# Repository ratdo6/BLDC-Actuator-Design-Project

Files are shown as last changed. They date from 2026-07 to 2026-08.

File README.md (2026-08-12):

<div align="center">

# BLDC Cycloidal Actuator - Quadruped Robot Leg

Inexpensive · Teensy 4.1 · Backdrivable · 3D printed · Moteus r4.11 FOC · CAN bus · Low backlash · ROS2 · BLDC motor



</div>

A custom cycloidal gearbox and actuator designed for a quadruped robot. Built around an 8308 BLDC motor, mjbots moteus r4.11, teensy 4.1, 3D printing, and ROS2. It takes advantage of the easy to manufacture cycloid geometry to create a cheap, but efficient actuator. This project is an opportunity for me to learn new skills and hone my strengths as an engineer. It is still in the early phases of development.  

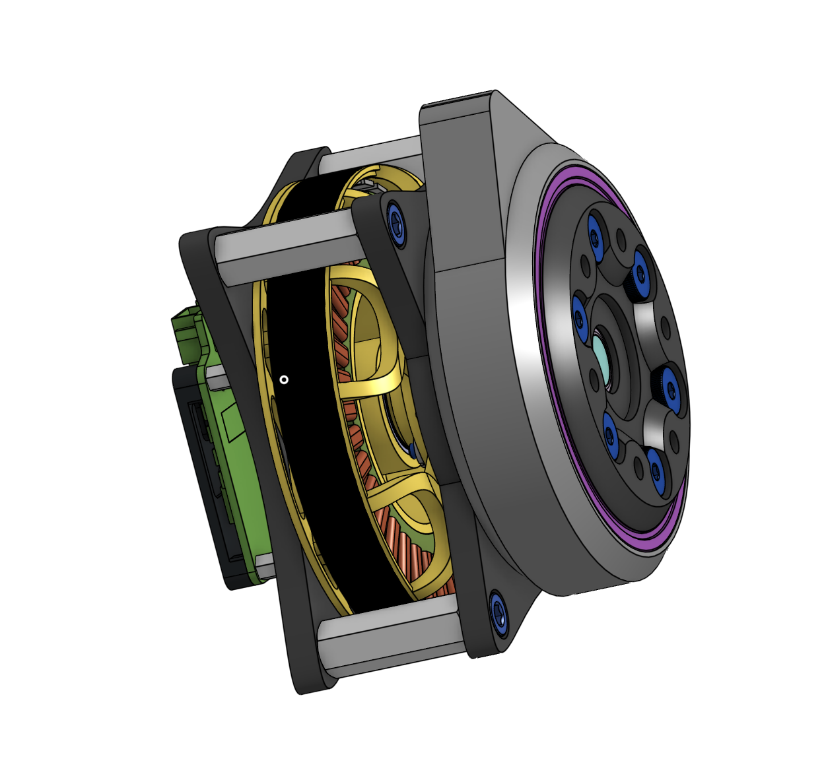
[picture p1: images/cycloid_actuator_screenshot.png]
Gearbox Assembly


## Goals

- **Plays nice with ROS2** — built to hook into ROS2 for the higher-level brain stuff (motion planning, orchestration, etc) 
- **Quadruped ready** — designed around a 12-DOF, 4-leg setup, but flexible enough to be repurposed
- **Precise joints** — actuator and drivetrain picks aim for minimal backlash, so movement stays accurate instead of sloppy
- **Custom electronics** — custom hub PCB handles CAN routing, power distrubution, and sensors avoiding the mess of breakout boards and jumper wires
- **3D-printable/sourceable** — Parts are deisgned to be FDM printer friendly or easily sourceable online 
- **Actually documented** — schematics, step files, firmware, design decisions, etc are all written up so I (or anyone else) can actually follow along and buid it

## Status

- [x] Cycloidal disc design, [Python visualizer](cycloidal_drive_visualizer/cycloidal_drive_visualizer.py)
- [x] Actuator design, [CAD](CAD/onshape_link.md)
- [x] [Bill of materials (BoM)](BOM/cycloidal_actuator_BOM.xlsx) (rough version available)
- [x] Calibrate Moteus r4.11 controllers to BLDC motors
- [x] 3D Printed protoype, tolerances dialed
- [ ] [KiCad PCBA schematic](Kicad-schematic/Teensy_BLDC_Build/Teensy_BLDC_Build.kicad_sch)
- [ ] Teensy 4.1 software
- [ ] Actuator efficiency and backlash testing
- [ ] Full 3DOF Leg Design
- [ ] Demo video(s)
- [ ] All CAD uploaded in .STEP & .STL formats

## Design Overview

Actuator architecture is built around a cycloid drive paired with a BLDC motor and FOC controller, chosen for its combination of high reduction ratio, low backlash, and shock tolerance. Crossed roller bearings are used at joint interface to handle combined radial and axial loads with minimal play. All design choices were picked with a legged robot in mind that has to absorb impact loads on every step.

- **Reduction ratio:** 9:1 (allows backdrivability, 10 roller pins, 9 lobes on disc)
- **E / Rr:** 0.500 (eccentricity (E) = 1.25mm)
- **Max pressure angle:** 20.03 degrees
- **Disc material:** PLA+ (future exploration into machined nylon, delrin, or aluminum planned)
- **BLDC motor:** Eagle Power 8308 90kv (cheap, powerful, and readily available)
- **FOC controller:** Moteus r4.11 (CAN bus interface, closed loop, compact form factor)

A custom built [cycloid disc parameters visualizer](cycloidal_drive_visualizer/cycloidal_drive_visualizer.py) was used to optimize variable selection before beginning CAD modeling
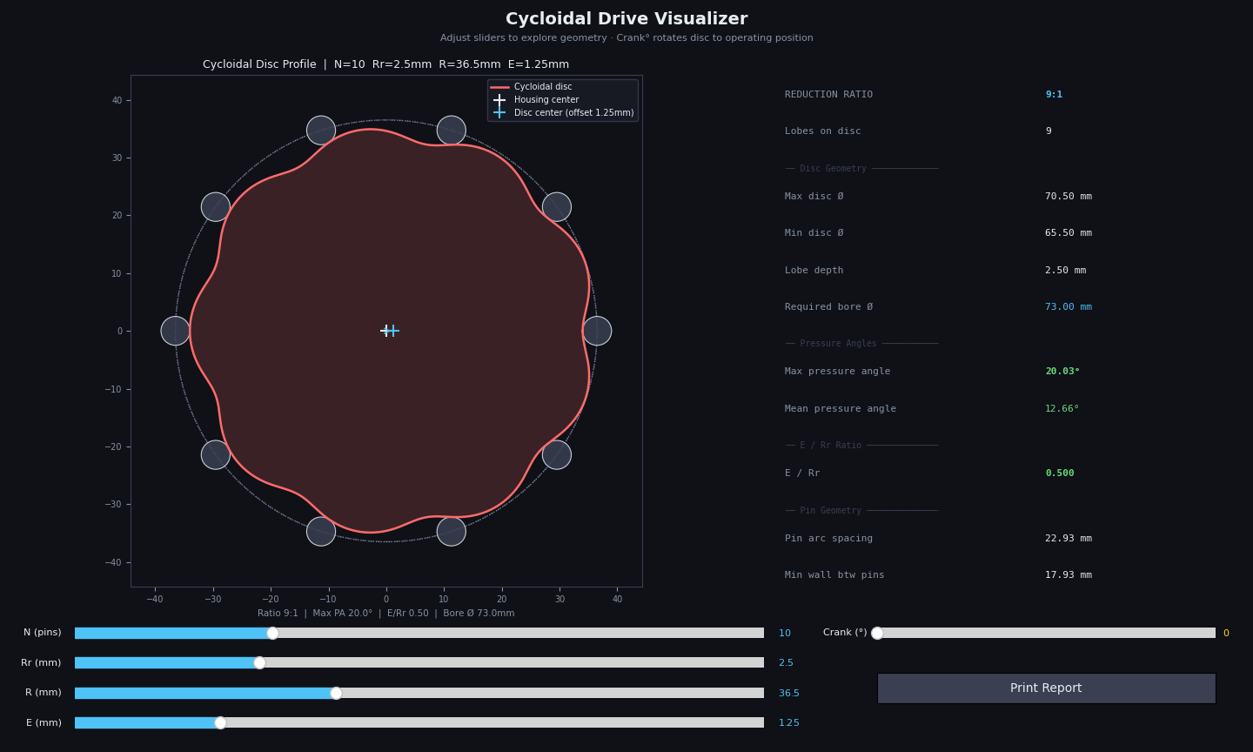
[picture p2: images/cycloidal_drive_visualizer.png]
Cycloidal Drive Visualizer


All CAD designed in OnShape. [View OnShape Document](https://cad.onshape.com/documents/7e181885841e2c0563f5ea8b/w/eb359d6e40468758aae61fb6/e/6c3a266b2d21d51902da69a4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)
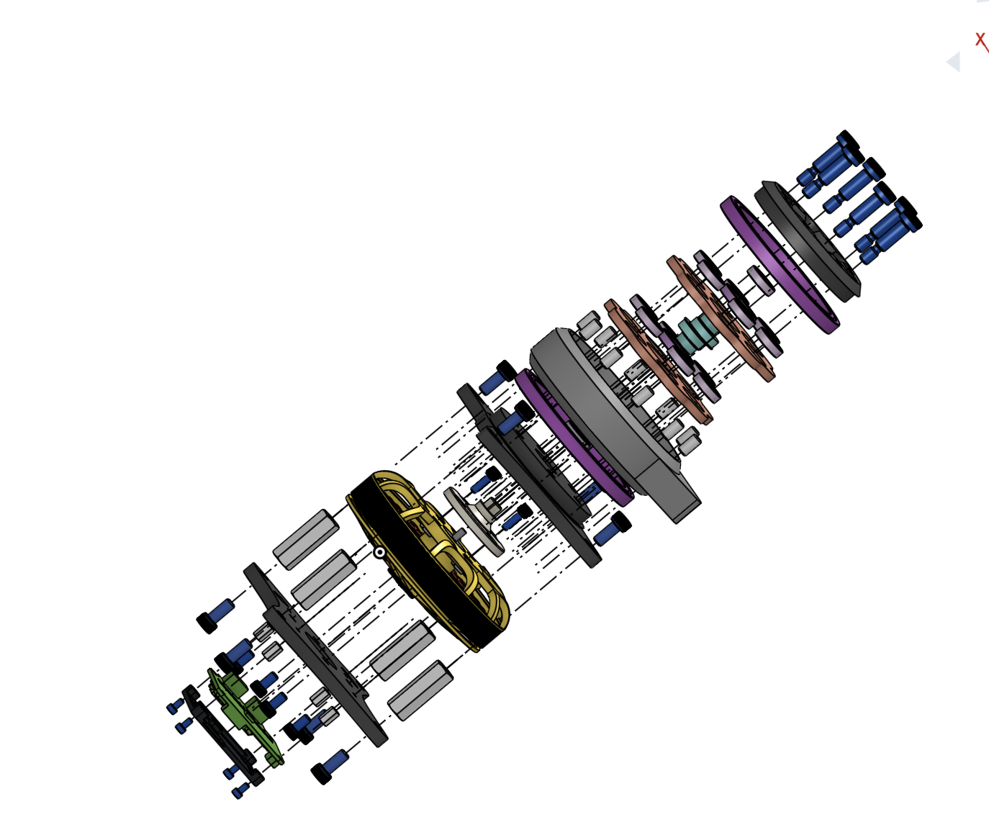
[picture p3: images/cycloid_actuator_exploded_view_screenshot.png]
Gearbox Assembly Exploded View


The actuator design centers on three choices that reinforce the same goal of minimal backlash, without needing industrial manufacturing access.

Cycloidal reduction was chosen over harmonic, planetary gearing, or capstan drives as the best fit for a self-built project. Harmonic drives offer great backlash performance but rely on flex-splines that are hard to source or machine yourself. Planetary gearboxes are easier to source but need precision-ground components to match cycloidal-level backlash. Capstan drives offer great performance for cost but are bulky and difficult to integrate in a compact leg assembly. Cycloidal drives split the difference — mechanically simple, tolerant of imperfect fabrication, compact, and low-backlash by design.

BLDC + FOC control (via the Moteus r4.11) keeps torque output smooth, which matters since any motor cogging gets amplified through the reduction stage. It also keeps the system modular, each joint handles its own closed-loop control over CAN, so the central hub just sends setpoints instead of managing low-level control for all 12 actuators.

Cross roller bearings at the output stage protect my backlash budget end-to-end. A precise cycloidal stage doesn't help if the output shaft has play. These bearings handle the combined radial/axial loads of stance and impact in a compact footprint, keeping joint mass reasonable for leg dynamics.

Together, these choices aim for locomotion-grade precision using parts and processes an individual builder can actually access.

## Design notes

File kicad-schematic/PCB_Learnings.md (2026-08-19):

# PCB Learnings:

The Teensy 4.1 is socketed, must preserve USB access, and avoid unsade USB/VIN back-power paths

Prefer the simplest physcically linear bus topology that matches the electrical constraints; adding more branches can make the system 
look simpler mechanically but usually hurts signal integrity and makes termination harder.

Mount the IMU rigidly on the PCB rather than making it removable, because mechanical rigidity improves motion measurement consistency 
and avoids extra cost and height.

Prefer removable, socketed mounting for high-value modules, but keep low-cost, vibration-sensitive signal parts permanently soldered 
for better reliability and measurement stability.

Prefer socketed or high-retention mounting for removable regulator modules over loose jumper-wire connections, 
because jumpers add failure points in vibrating systems.

For robot hubs that need orientation data, 
a fused IMU with onboard sensor fusion is often the cleaner choice than raw inertial sensing plus host-side fusion.

Verify the physical-layer transceiver is CAN-FD rated before committing to the design; 
classic CAN transceivers are not suitable for the higher data-phase bitrate.

For a central-hub robot, it is often cleaner to treat the hub as a passive CAN junction and keep motor power distribution on a separate board, 
so the communication board only has to handle logic, transceivers, and low-power peripherals.

A linear daisy-chain CAN-FD bus with short stubs and end-only termination 
can still be practical over roughly 4.5 m for a small multi-node robot.

If the processor only has one CAN-FD-capable controller, 
two independent CAN-FD buses may require an external CAN-FD controller or a different MCU architecture.

Classic CAN transceivers are not suitable for CAN-FD data-phase rates;
the CAN physical layer choice must be checked against the actual bus protocol requirements, not just the arbitration bitrate.

# Project Specification

## Project Overview
- Teensy 4.1 carrier and central control hub for a quadruped robot.
- Accepts 24 VDC and provides local 5 V power through a removable Pololu D24V50F5 module.
- Interfaces one Teensy 4.1 CAN-FD controller to twelve moteus r4.11 motor controllers on one linear CAN-FD bus.
- Includes a permanently assembled fused 9-DoF IMU.

## Intended Use
- Prototype and robot-development platform mounted near the center of a quadruped.
- Initial use may test one three-motor leg; the completed wiring supports all four legs.
- Expected CAN cable length is approximately 4.5 m end-to-end in the complete robot.

## What the Device Should Do
- Power a socketed Teensy 4.1 from a 24 V robot supply.
- Communicate with up to twelve moteus r4.11 FOC controllers.
- Acquire fused orientation and motion data.
- Permit rapid replacement of the Teensy and DC-DC module.
- Provide accessible test points and mechanically secure robot-ready connections.

## Main Features
- XT30 24 VDC input used only by the hub.
- Socketed Pololu D24V50F5 5 V regulator module.
- Socketed Teensy 4.1.
- One MCP2562FD-class CAN-FD transceiver with 3.3 V VIO and at least 5 Mbit/s capability.
- Two JST-PH 3-pin CAN connectors: CANH, CANL, GND.
- BNO085/BNO086-class IMU using SPI.
- Input protection, local decoupling, status indication, and test access.
- Four M2.5 corner mounting holes.

## System Architecture
```mermaid
flowchart TD
    VIN["24 VDC XT30 Input"] --> PROT["Input Protection"]
    PROT --> POL["Socketed Pololu D24V50F5"]
    POL --> V5["5 V Rail"]
    V5 --> TEENSY["Socketed Teensy 4.1"]
    TEENSY --> V3.3["3.3 V Rail"]
    V3.3 --> IMU["BNO08x IMU"]
    V3.3 --> CANPHY["CAN-FD Transceiver"]
    TEENSY --> IMU
    TEENSY <--> CANPHY
    CANPHY <--> CAN_A["CAN Connector A"]
    CANPHY <--> CAN_B["CAN Connector B"]
    CAN_A <--> LEGS_A["Six moteus r4.11 Controllers"]
    CAN_B <--> LEGS_B["Six moteus r4.11 Controllers"]
```

## Hardware Subsystems
### Power
- XT30 input, nominal 24 VDC.
- Add reverse-polarity and transient protection appropriate for wiring in a motorized robot.
- Pololu D24V50F5 remains removable through high-retention socket headers and mechanical support provisions.
- Teensy VIN receives regulated 5 V; do not connect an external 5 V source simultaneously without respecting Teensy power-input constraints.

### Compute
- Teensy 4.1 on removable female socket headers.
- Use the Teensy CAN3/CAN-FD-capable interface.
- Preserve USB connector access, reset/program access, and SD-card access where practical.

### CAN-FD
- One physical bus at 1 Mbit/s arbitration and 5 Mbit/s data phase.
- Two connectors represent the two physical directions of one linear bus, not independent channels.
- No onboard 120 ohm termination in the default design. Termination belongs at the two physical ends; the user has external JST-PH terminator boards for reduced configurations.
- CANH/CANL routing must be short, symmetric, and treated as a controlled differential pair.
- Add CAN-line ESD protection with low capacitance suitable for CAN-FD.

### IMU
- Permanently assembled BNO085/BNO086-class fused IMU.
- SPI interface preferred for reliable higher-rate communication.
- Mount near the board center, rigidly, with clear axis markings.
- Keep away from the switching regulator, high-current paths, and magnetic materials where possible.

## Interfaces and Connections
| Interface | Connector or Device | Signals |
|---|---|---|
| Power input | XT30 | +24V, GND |
| CAN direction A | JST-PH 3-pin | CANH, CANL, GND |
| CAN direction B | JST-PH 3-pin | CANH, CANL, GND |
| Host compute | Teensy 4.1 sockets | 5V, 3.3V, GND, CAN TX/RX, SPI, interrupt/reset signals |
| Regulator | Pololu D24V50F5 sockets | VIN, GND, VOUT and applicable control pins |
| Debug/test | Test points | 24V, 5V, 3.3V, GND, CANH, CANL, CAN TX, CAN RX, SPI CS/IRQ |

## Power and Runtime Expectations
- The hub does not distribute motor power.
- Continuous power is expected to remain well below the Pololu module's 5 A rating.
- Design for at least 0.75 A available on the 5 V rail to cover Teensy activity, USB peripherals, CAN dominant-state current, IMU, indicators, and margin.

## Power Tree and Power Budget
| Rail | Load | Estimated Typical | Design Peak |
|---|---|---:|---:|
| 5 V | Teensy 4.1 and attached local functions | 150-250 mA | 500 mA |
| 5 V | CAN-FD transceiver bus supply | 10-40 mA | 80 mA |
| 3.3 V | BNO08x IMU | 5-15 mA | 25 mA |
| 3.3/5 V | LEDs and support circuitry | 5-15 mA | 30 mA |
| 5 V total | All hub loads plus margin | about 300 mA | 750 mA design target |

At 24 V and 90 percent conversion efficiency, a 0.75 A peak at 5 V corresponds to approximately 0.174 A from the 24 V input. Protection and connectors should be sized above this with transient margin. Final values must be checked against selected part datasheets and any later Teensy USB/peripheral loading.

## Manufacturing and Assembly Expectations
- Four-layer PCB preferred for solid ground/reference planes and robust CAN-FD routing.
- Manufacturer assembles all SMD parts, connectors, protection, and IMU.
- Teensy and Pololu modules remain removable and may be installed after PCBA delivery.
- Choose commonly stocked, non-obsolete parts where possible.
- Include fiducials, readable polarity and pin-1 markings, connector pin labels, IMU axes, and board revision marking.

## Firmware-Relevant Hardware Requirements
- Teensy 4.1 CAN3 configured for CAN-FD, 1 Mbit/s nominal and 5 Mbit/s data rate.
- SPI interface to BNO08x with dedicated chip-select, interrupt, and reset as required.
- Maintain access to Teensy USB programming and program/reset controls.
- Firmware must support operation with one to twelve moteus nodes and report CAN errors.

## Physical Design Expectations
- Compact rectangular board sized after footprint and connector placement.
- Four M2.5 clearance mounting holes at the corners.
- XT30 and CAN connectors accessible from board edges.
- Teensy USB connector accessible at an edge.
- IMU close to mechanical center with axis legend on silkscreen.
- Provide mechanical support/retention provisions for both removable modules.

## Important Design Decisions
- One shared linear CAN-FD bus was selected because Teensy 4.1 exposes one CAN-FD-capable controller.
- Two CAN connectors represent opposite directions of the bus; each direction daisy-chains through six moteus controllers.
- MCP2562FD-class transceiver selected over SN65HVD230 because SN65HVD230 is unsuitable for the 5 Mbit/s CAN-FD data phase.
- Teensy and Pololu modules are removable; IMU and CAN interface are permanently assembled for signal integrity and mechanical stability.
- No onboard termination; external termination is placed at actual bus ends.

## Assumptions
- The complete cable assembly is a true linear trunk with very short moteus stubs.
- The robot supply can experience motor-related transients; input protection will be included even though motor power is routed elsewhere.
- JST-PH cable pin order will be fixed consistently as CANH, CANL, GND and clearly marked.
- Environmental target is indoor prototype robotics rather than sealed outdoor deployment.

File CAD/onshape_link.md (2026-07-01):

# CAD Files

All CAD was deisgned in OnShape.

[View OnShape Document](https://cad.onshape.com/documents/7e181885841e2c0563f5ea8b/w/eb359d6e40468758aae61fb6/e/6c3a266b2d21d51902da69a4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)

## Notes
- Primary design tool: OnShape
- Exported formates: .step

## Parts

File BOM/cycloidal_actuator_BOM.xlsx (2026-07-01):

CYCLOIDAL ACTUATOR — BILL OF MATERIALS
8308 Motor | 9:1 Ratio Cyloidal Actuator
# | Name | Description / Spec | Qty | Unit | Unit Cost ($) | Total Cost ($) | Link
BEARINGS
1 | KA025XP0 BEARING | KA025XP0, Crossed Roller Bearing, OD 72.2 x ID 63.5 x W 6.35 mm | 2 | ea | $10.77 | $21.54 | https://www.alibaba.com/product-detail/KA025XP0-KA025XPO-Size-63-5x76-2x6_1600117064347.html
2 | 6700ZZ BEARING | 6700ZZ, Deep Groove Ball Bearing, ID 10 × OD 15× W 4 mm | 14 | ea | $0.74 | $10.36 | https://www.amazon.com/uxcell-Deep-Groove-Bearings-Rollers-Skateboard/dp/B0D9DLHGV4
3 | 6702ZZ BEARING | 6702ZZ, Deep Groove Ball Bearing, ID 15 x OD 21 x W 4 mm | 2 | ea | $0.95 | $1.90 | https://www.amazon.com/uxcell-Deep-Groove-Bearings-Rollers-Skateboard/dp/B0D9DMY13D
ROLLERS
4 | M5x10mm DOWEL PIN | Dowel Pin, M5 x 10mm 304 Stainless Steel | 10 | ea | $0.24 | $2.40 | https://www.amazon.com/HARFINGTON-Stainless-Cylindrical-Furniture-Installation/dp/B0FW41S6QM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
CUSTOM PARTS
5 | CYCLOIDAL DISC | FDM Printed with PLA+, 40% Infill | 2 | ea | $1.00 | $2.00 | N/A
6 | ECCENTRIC SHAFT | FDM Printed with PLA+, 40% Infill | 1 | ea | $1.00 | $1.00 | N/A
7 | SHAFT COUPLER | FDM Printed with PLA+, 40% Infill | 1 | ea | $1.00 | $1.00 | N/A
8 | HOUSING | FDM Printed with PLA+, 40% Infill | 1 | ea | $2.00 | $2.00 | N/A
9 | TOP HOUSING PLATE | FDM Printed with PLA+, 40% Infill | 1 | ea | $1.00 | $1.00 | N/A
10 | BACK STRUCTURAL PLATE | FDM Printed with PLA+, 40% Infill | 1 | ea | $2.00 | $2.00 | N/A
11 | FRONT STRUCTURAL PLATE | FDM Printed with PLA+, 40% Infill | 1 | ea | $2.00 | $2.00 | N/A
ELECTRONICS
12 | MOTOR CONTROLLER | MJBots Moteus r4.11 FOC Based Controller | 1 | ea | $60.00 | $60.00 | https://mjbots.com/products/moteus-r4-11
MOTOR
13 | MOTOR | Eaglepower 8308 Brushless Motor KV90 | 1 | ea | $70.00 | $70.00 | https://www.aliexpress.us/item/3256807740566993.html?src=google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
FASTENERS & MISC
14 | M4x14mm SCREW | Black-Oxide Alloy Steel Socket Head Screw, M4x0.7 Thread, 14mm Long | 8 | ea | $0.15 | $1.20 | https://www.mcmaster.com/91290A150/
16 | M2.5x6mm SCREW | Black-Oxide Alloy Steel Socket Head Screw, M2.5x0.45 Thread, 6mm Long | 4 | ea | $0.24 | $0.96 | https://www.mcmaster.com/91290A101/
17 | M2.5x8mm STANDOFF | Lightweight Aluminum Female Threaded Hex Standoff, 4.5mm Hex Size, 8mm Long, M2.5x0.45 Thread | 4 | ea | $0.52 | $2.08 | https://www.mcmaster.com/95947A003/
18 | M5 SHOULDER SCREW | 304 Stainless Steel Shoulder Bolt, 6mm Shoulder Dia, 16mm Shoulder Length, M5x0.8 Thread, Hex Socket Shoulder Bolt | 6 | ea | $0.98 | $5.88 | https://www.amazon.com/MECCANIXITY-Stainless-Hydraulic-Injection-Industries/dp/B0FDQWNKWD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
19 | M4x30mm STANDOFF | Lightweight Aluminum Female Threaded Hex Standoff, 6mm Hex Size, 30mm Long, M4x0.7 Thread | 4 | ea | $2.20 | $8.80 | https://www.mcmaster.com/95947A767/
TOTAL COST |  |  |  |  |  | $196.12
TOTAL PART COUNT |  |  |  |  |  | 64

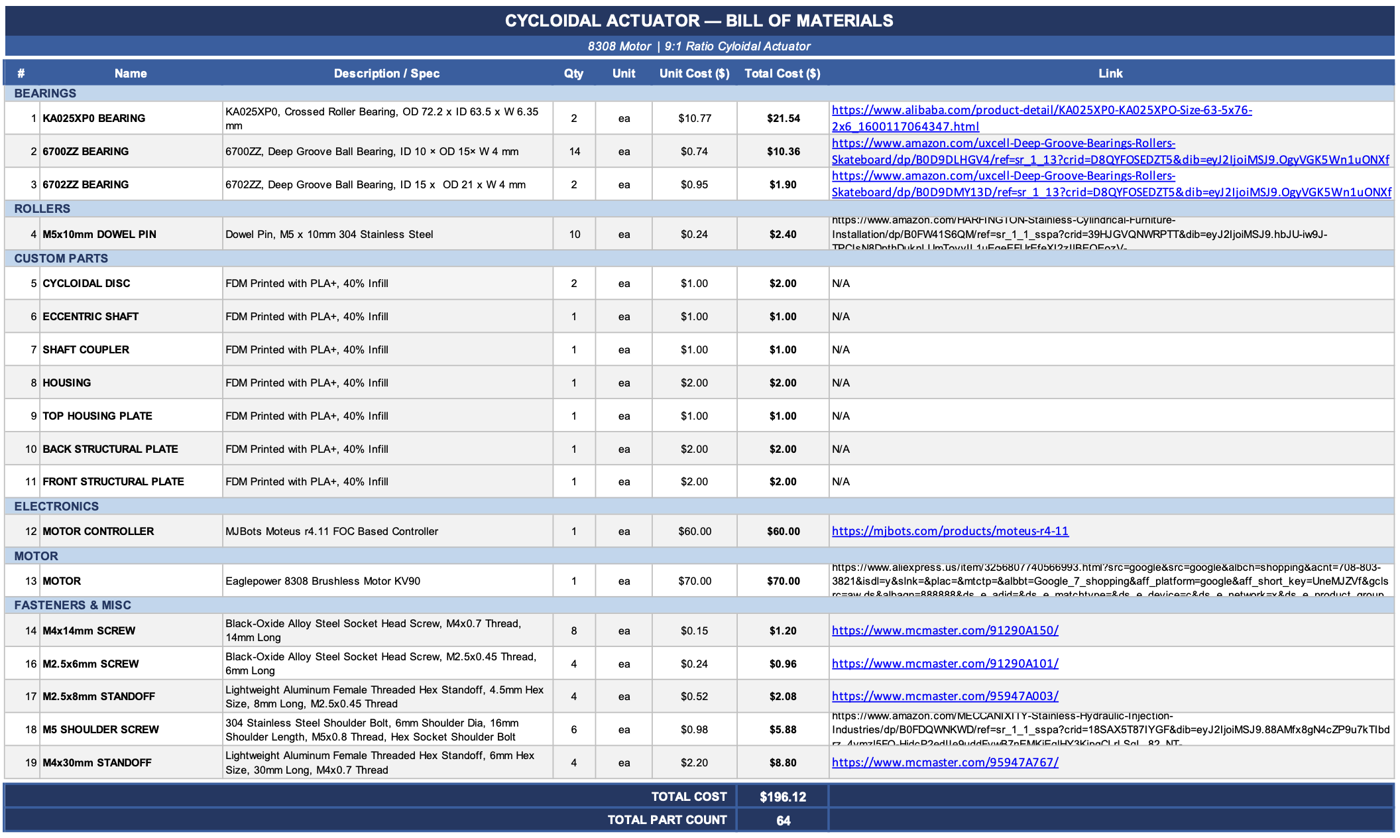
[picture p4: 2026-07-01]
BOM/cycloid_actuator_BOM_screenshot.png

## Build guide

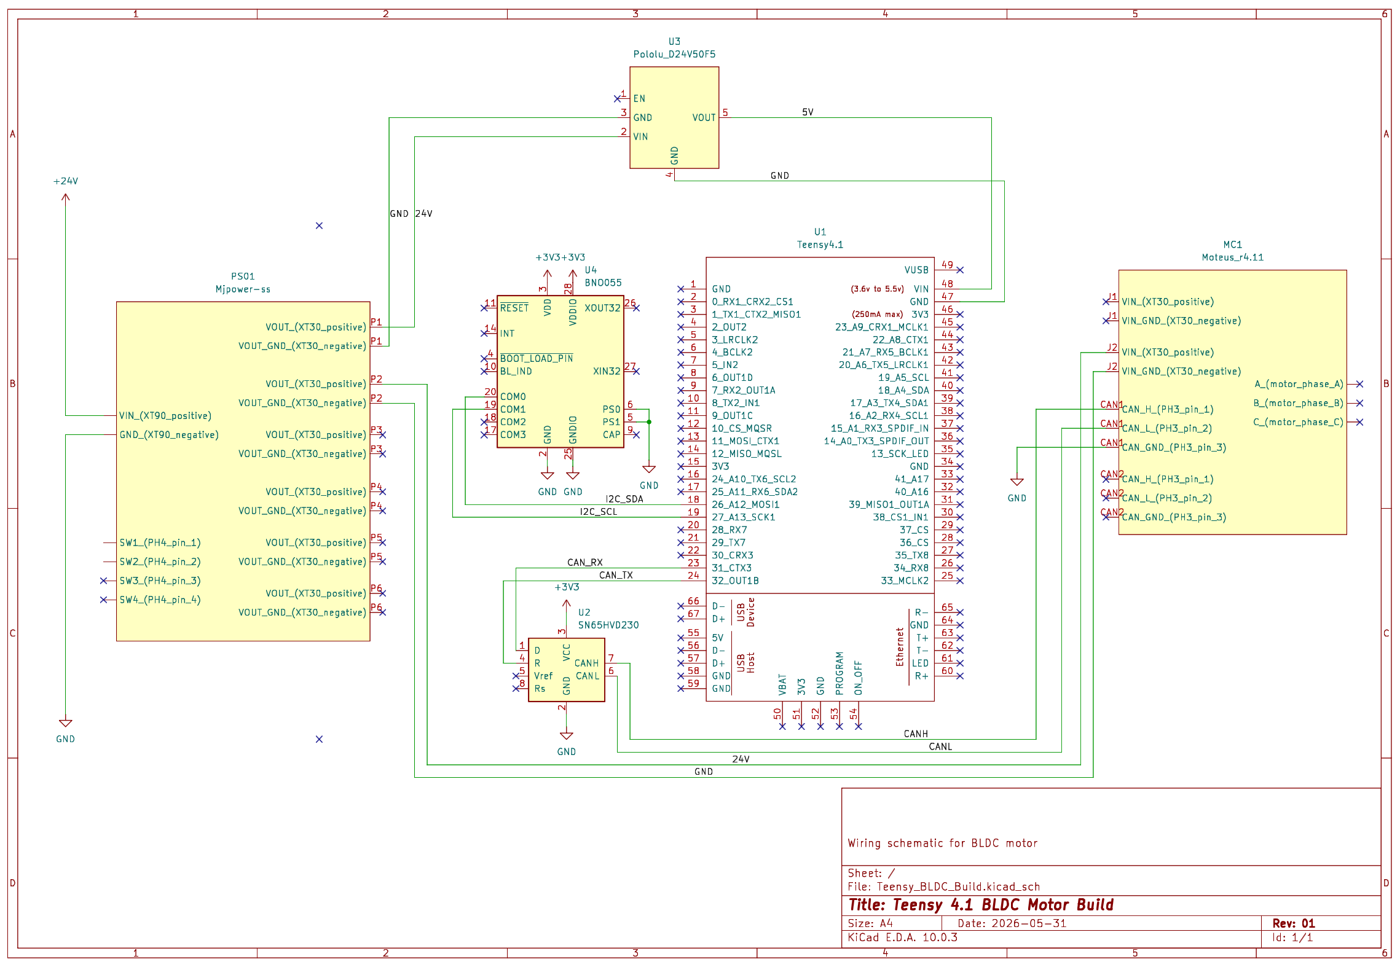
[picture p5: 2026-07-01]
kicad-schematic/Teensy_BLDC_Build/Teensy_BLDC_Build_screenshot.png

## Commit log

2026-06-01 Wiring schematic upload
2026-06-02 Add KiCad schematic for Teensy 4.1 BLDC motor build
    [Teensy_BLDC_Build.kicad_sch]
2026-06-08 Added Actuator BOM
    [cycloidal_actuator_BOM.xlsx]
2026-07-01 Update BOM
2026-07-01 Upadate cycloidal actuator BOM
    [cycloidal_actuator_BOM.xlsx]
2026-07-01 Add Schematic Screenshot
2026-07-01 Add CAD assembly photos
2026-08-04 Update README goals/design overview, add PCBA build folder
    [Quadruped_PCBA_Build.kicad_pcb, Quadruped_PCBA_Build.kicad_sch]
2026-08-12 Add calibration data for CAN01 (leg1 joint3)
2026-08-12 Update README.md checklist to include motor controller callibration
2026-08-19 Add PCB_Learnings.md file to organize PCB design goal notes
